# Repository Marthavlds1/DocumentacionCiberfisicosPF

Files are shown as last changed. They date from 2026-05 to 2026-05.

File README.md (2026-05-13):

# Planchado Express — Documentación Técnica

Documentación técnica del proyecto **Planchado Express**, desarrollado como parte de la asignatura de **Sistemas Ciberfísicos** en la **Universidad Iberoamericana (IBERO)**, Primavera 2026.

---

## Documentación en línea

La documentación completa del proyecto está disponible en:

**[marthavlds1.github.io/DocumentacionCiberfisicosPF](https://marthavlds1.github.io/DocumentacionCiberfisicosPF)**

---

## Descripción del proyecto

Planchado Express es un sistema ciberfísico integrado que automatiza el proceso de planchado de prendas textiles en un entorno industrial. El usuario registra su prenda en la interfaz web y obtiene un código QR de seguimiento; a partir de ese momento el sistema opera de forma completamente autónoma: clasifica la prenda mediante inteligencia artificial, ejecuta la rutina de planchado con un robot colaborativo UR3 y entrega la prenda mediante una banda transportadora con actuadores de salida.

### Componentes principales del sistema

| Componente | Tecnología |
| :--- | :--- |
| Robot colaborativo | Universal Robots UR3 |
| Control industrial | PLC Allen Bradley Micro850 |
| Orquestador del sistema | Raspberry Pi 3 — `rutina_maestra.py` |
| Clasificación por IA | Keras / TensorFlow — `keras_model.h5` |
| Control de periféricos | ESP32 (pistón eléctrico + torreta de señalización) |
| Base de datos y autenticación | Firebase (Auth, Firestore, Realtime DB, Storage) |
| Backend API | Flask — Docker — Render |
| Interfaz web del cliente | GitHub Pages |

---

## Estructura del repositorio

```
DocumentacionCiberfisicosPF/
├── _config.yml
├── _includes/
│   ├── head_custom.html
│   └── footer_custom.html
├── assets/
│   └── css/custom.css
├── index.md
├── 01-contexto.md
├── 02-problema.md
├── 03-objetivos.md
├── 04-descripcion-funcional.md
├── 05-algoritmo.md
├── 06-arquitectura.md
├── 07-diseno-mecanico.md
├── 08-diseno-electronico.md
├── 09-control-programacion.md
├── 10-iot-nube-interfaz.md
├── 11-simulacion.md
├── 12-materiales-costos.md
├── 13-metodologia.md
├── 14-resultados.md
├── 15-problemas.md
├── 16-evidencia.md
├── 17-referencias.md
└── uso-ia.md
```
---

## Equipo de desarrollo

| Integrante | Programa |
| :--- | :--- |
| Luis Cortés Muñoz | Ingeniería Mecatrónica — IBERO |
| Emmanuel Iturbide Rebolledo | Ingeniería Mecatrónica — IBERO |
| Alexander Moncada Rivas | Ingeniería Mecatrónica — IBERO |
| Martha Valdés Cruz | Ingeniería Mecatrónica — IBERO |
| Renata Badillo Cabrera | Ingeniería Mecatrónica — IBERO |
| Camila Sánchez Guevara | Ingeniería Mecatrónica — IBERO |

**Cuerpo docente:** Mtro. Joel Arango Ramírez · Dr. Huber Girón Nieto

---

## Referencias del proyecto

| Recurso | URL |
| :--- | :--- |
| Documentación técnica | [marthavlds1.github.io/DocumentacionCiberfisicosPF](https://marthavlds1.github.io/DocumentacionCiberfisicosPF) |
| Interfaz web del cliente | [luiscortesmunoz.github.io/Planchaduria](https://luiscortesmunoz.github.io/Planchaduria/) |
| Backend API (Render) | [docker-planchaduria.onrender.com](https://docker-planchaduria.onrender.com) |
| Diagrama de arquitectura | [Miro — Arquitectura Ciberfísica](https://miro.com/app/live-embed/uXjVGEpRJUk=/) |

---

## Tecnologías utilizadas

`Python` `URScript` `Flask` `Firebase` `Docker` `Keras` `TensorFlow` `Modbus TCP` `Raspberry Pi` `ESP32` `PLC Micro850` `Jekyll` `Just the Docs`

---

Universidad Iberoamericana · Ingeniería Mecatrónica · Sistemas Ciberfísicos · Primavera 2026

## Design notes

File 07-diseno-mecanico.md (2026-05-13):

---
layout: default
title: Diseño Mecánico
nav_order: 8
---

# Diseño Mecánico

## Estructura general del sistema

La estructura física de **Planchado Express** está compuesta por una **banda transportadora lineal** con tres estaciones de sensado y una plataforma de montaje para el robot UR3. El recorrido de la prenda va desde la entrada (sensor S1) hasta la salida por gancho (sensor S3).

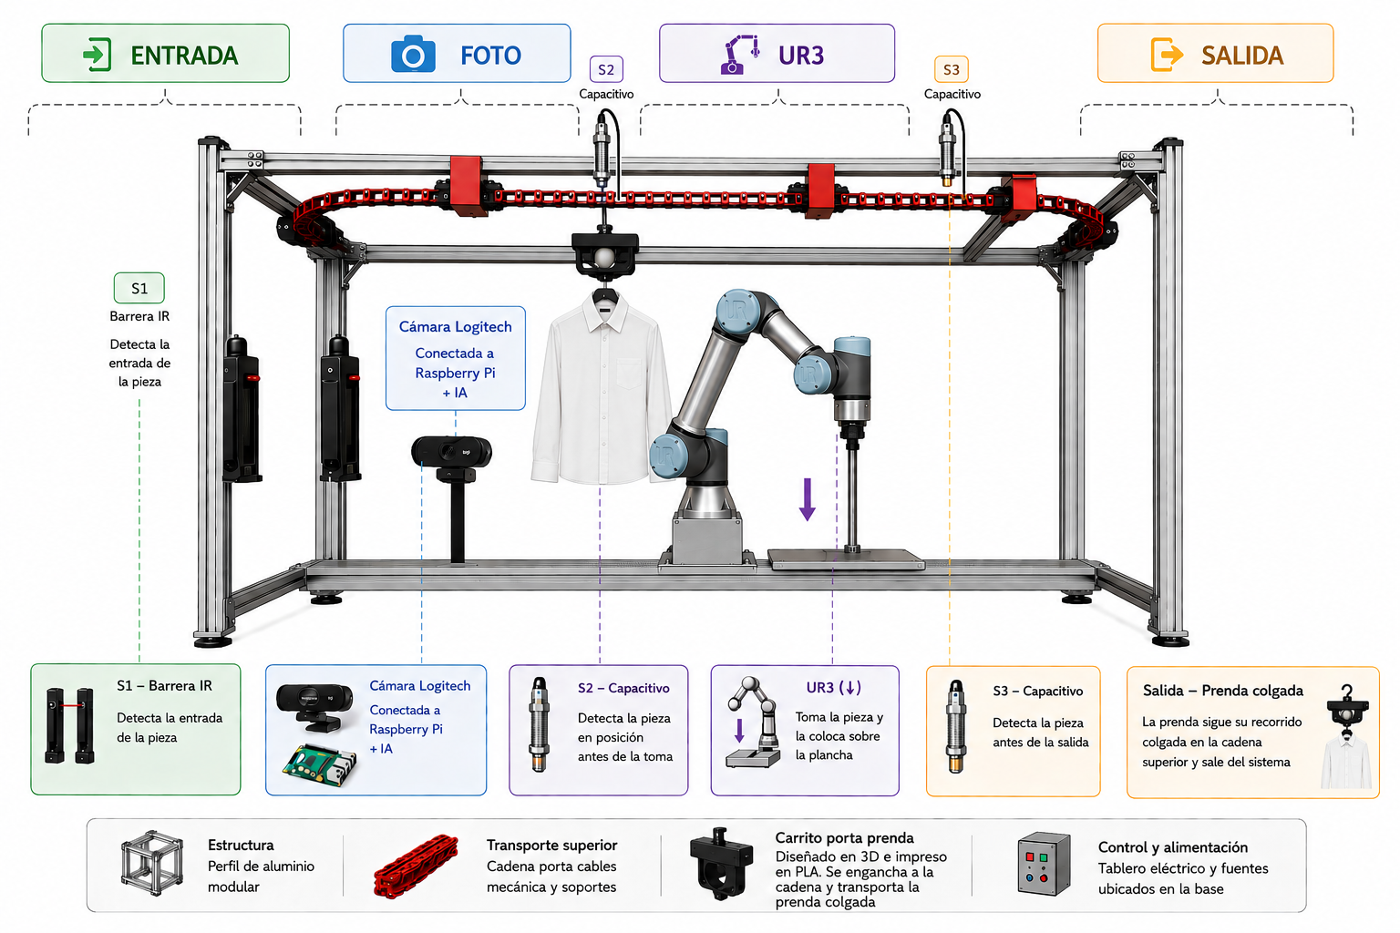
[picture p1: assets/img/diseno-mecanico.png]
Estructura general del sistema

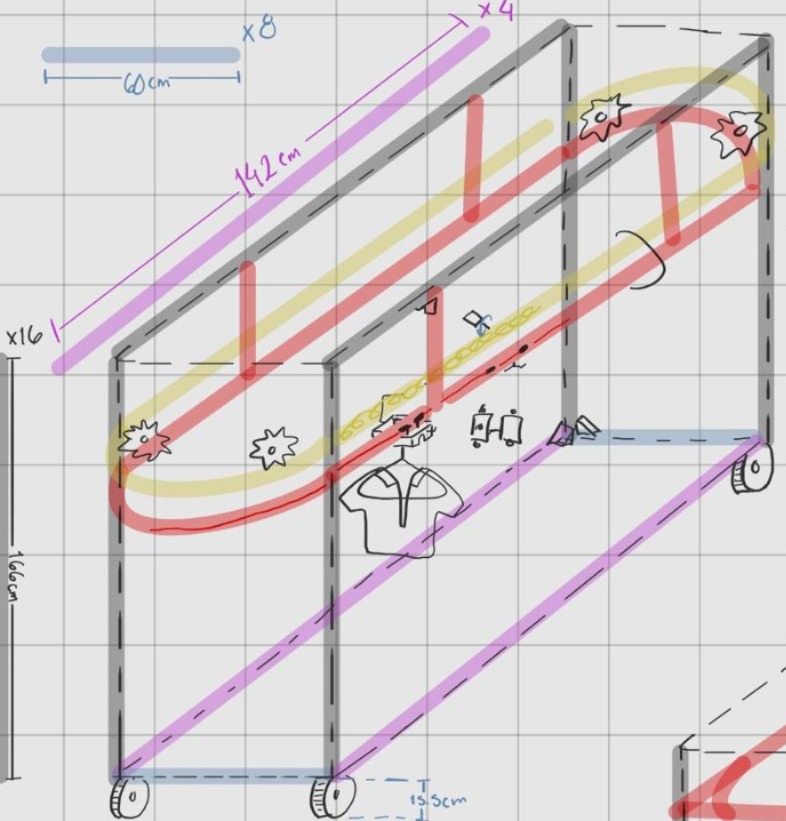
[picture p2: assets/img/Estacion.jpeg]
Medidas de estacion


---

## Robot UR3 — Especificaciones físicas

| Parámetro | Valor |
| :--- | :--- |
| Modelo | Universal Robots UR3 |
| Tipo | Robot colaborativo (Cobot) |
| Grados de libertad | 6 DOF |
| TCP configurado | `p[0.0, 0.0, 0.0777, 0.0, 0.0, 0.0]` |
| Payload configurado | 0.1 kg |
| Voltaje de herramienta | 24 V |
| Gravedad configurada | `[0.0, 0.0, 9.82]` m/s² |
| Efector final | Agarrador impreso en PLA (fabricación propia) |
| Herramienta montada | Plancha eléctrica comercial |
| Waypoints por rutina | 7 puntos calibrados |

---

## Efector final — Agarrador PLA

El agarrador del efector final fue **diseñado y fabricado mediante impresión 3D** en filamento PLA. Está dimensionado para:

- Sostener con seguridad la plancha comercial utilizada.
- Garantizar la geometría de contacto correcta con la superficie de la prenda durante las trayectorias de planchado.
- Resistir el peso y el calor transmitido por la plancha durante la operación continua.

---

## Banda transportadora

| Parámetro | Descripción |
| :--- | :--- |
| Tipo | Banda lineal motorizada |
| Dirección | Unidireccional (adelante) |
| Control | PLC Micro850 (coils `000001`, `000002`, `000003`) |
| Estaciones | Entrada → Foto → UR3 → Salida |
| Mecanismo de salida | Pistón eléctrico + gancho lateral |

---

## Actuador de salida — Pistón eléctrico

El pistón eléctrico está controlado por el **ESP32** mediante comandos seriales desde la Raspberry Pi. Al activarse, empuja lateralmente la prenda planchada hacia el gancho de salida donde el cliente la recoge.

| Parámetro | Valor |
| :--- | :--- |
| Tipo | Actuador lineal eléctrico |
| Control | ESP32 vía serial USB |
| Tiempo extendido | 9 segundos |
| Tiempo de espera tras cerrar | 9 segundos |
| Función | Expulsar prenda al gancho de salida |

---

## Piezas diseñadas e impresas en 3D

Todas las piezas fueron diseñadas en CAD y fabricadas mediante impresión 3D en filamento PLA. Los archivos `.stl` están disponibles en la carpeta `0_IMPRIMIR/` del repositorio.

[Descargar archivos STL](assets/0_IMPRIMIR){: .btn .btn-outline }

| Pieza | Vista previa | Función |
| :--- | :---: | :--- |
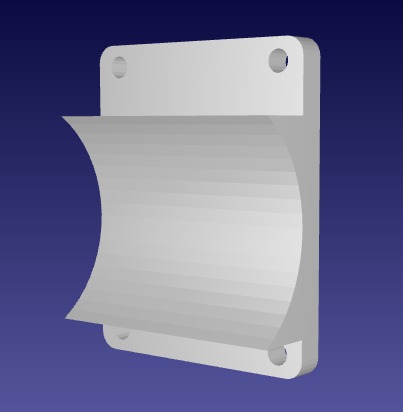
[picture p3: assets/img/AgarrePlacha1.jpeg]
Agarre Plancha 1
| Agarre de Plancha 1 |  | Sujeción principal de la plancha al efector del UR3 |
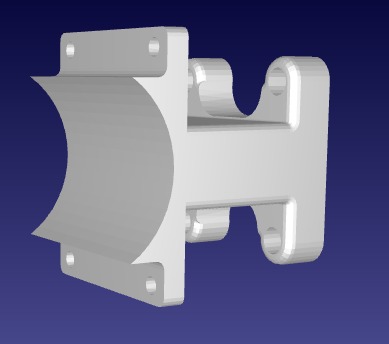
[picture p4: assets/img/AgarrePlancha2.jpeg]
Agarre Plancha 2
| Agarre de Plancha 2 |  | Pieza complementaria del agarre de plancha |
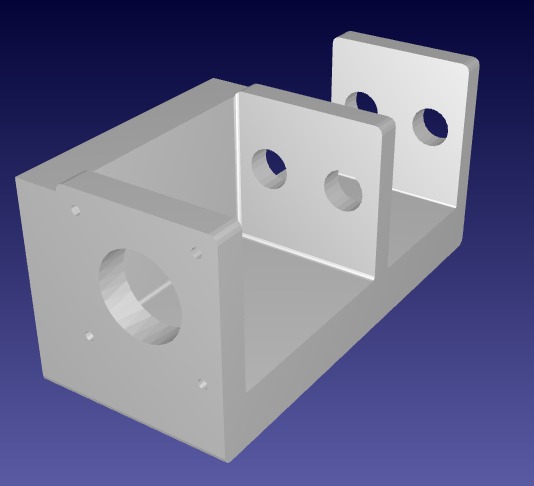
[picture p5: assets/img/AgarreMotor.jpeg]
Agarre Motor
| Agarre Motor a Pasos |  | Montaje del motor Nema 17 en la estructura |
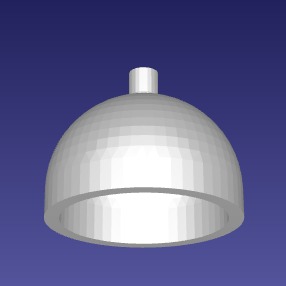
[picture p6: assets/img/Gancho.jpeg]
Gancho
| Gancho |  | Gancho de salida para entrega de prenda |
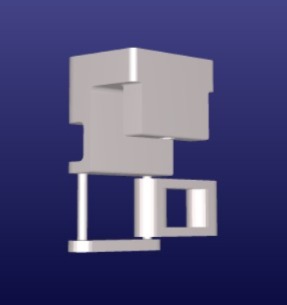
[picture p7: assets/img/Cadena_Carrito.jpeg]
Cadena Ganchito
| Cadena Ganchito |  | Eslabón de cadena para sistema de transporte |
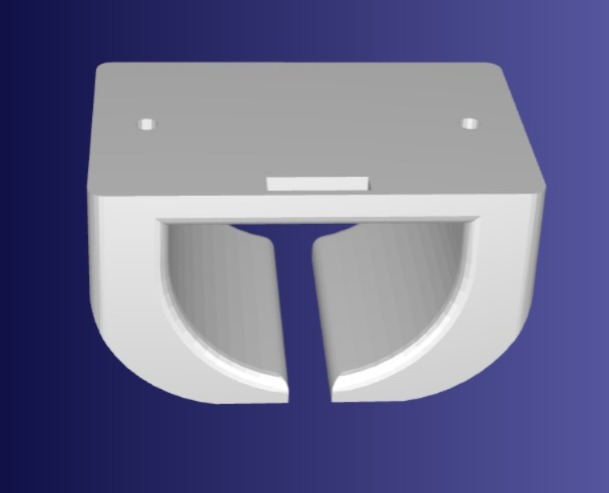
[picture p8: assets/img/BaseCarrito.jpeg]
Carrito Base
| Carrito Base |  | Base del carrito sobre la banda |
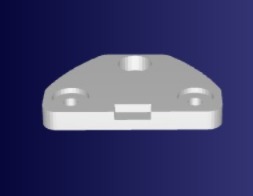
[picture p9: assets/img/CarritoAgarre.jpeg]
Carrito Agarre
| Carrito Agarre |  | Agarre superior del carrito |
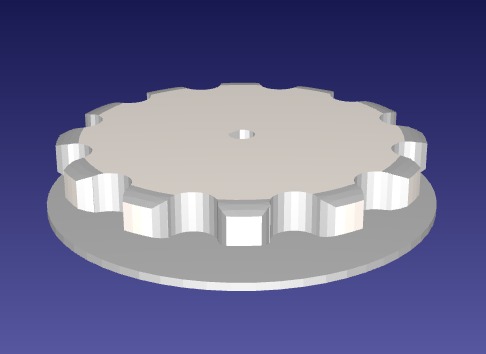
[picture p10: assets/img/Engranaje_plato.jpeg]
Engranaje Plato
| Engranaje Plato |  | Engranaje de transmisión principal |
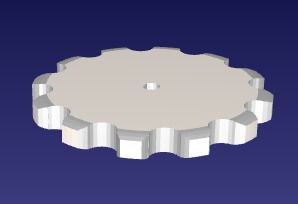
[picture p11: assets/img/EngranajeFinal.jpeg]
Engranaje Final
| Engranaje Final |  | Engranaje de salida del sistema |
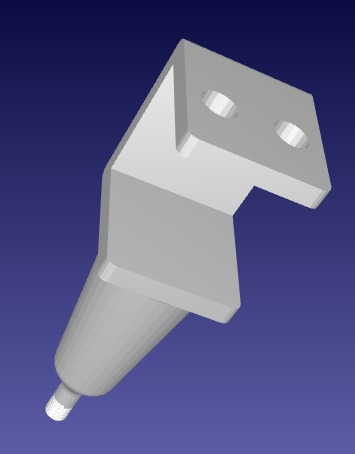
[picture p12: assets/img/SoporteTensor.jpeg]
Soporte Tensor
| Soporte Tensor |  | Soporte para sistema de tensado de banda |
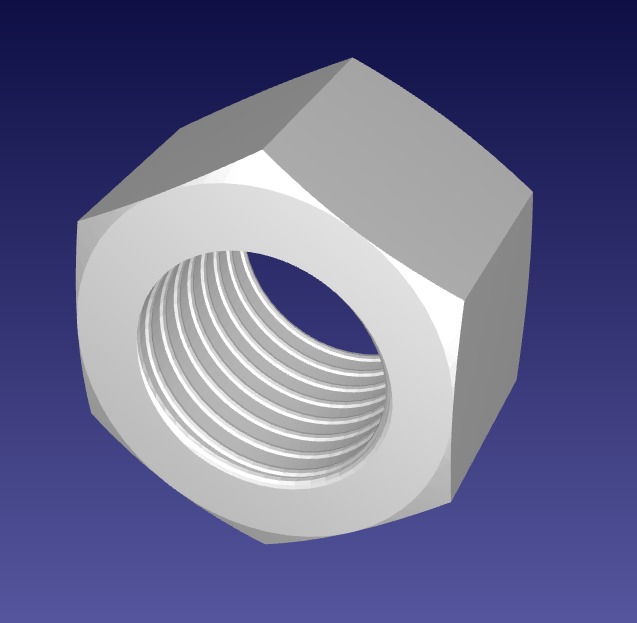
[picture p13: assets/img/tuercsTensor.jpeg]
Tuerca Tensor
| Tuerca Tensor |  | Elemento de ajuste del tensor |
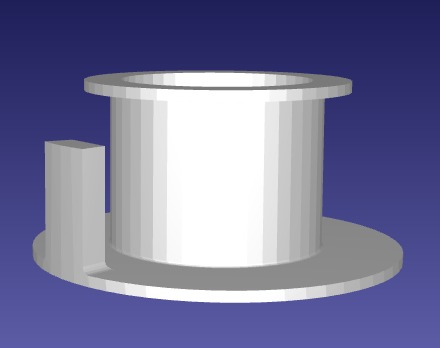
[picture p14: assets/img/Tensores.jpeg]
Tensores
| Tensores |  | Componentes de tensado de la banda |
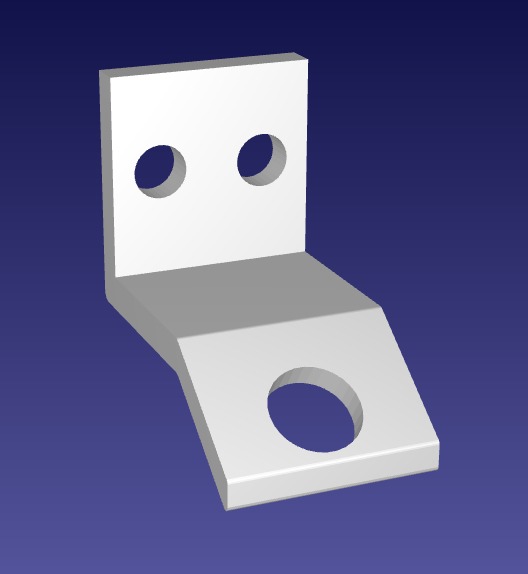
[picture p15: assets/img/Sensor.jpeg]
Sensores
| Sensores |  | Soporte/montaje para sensores inductivos |
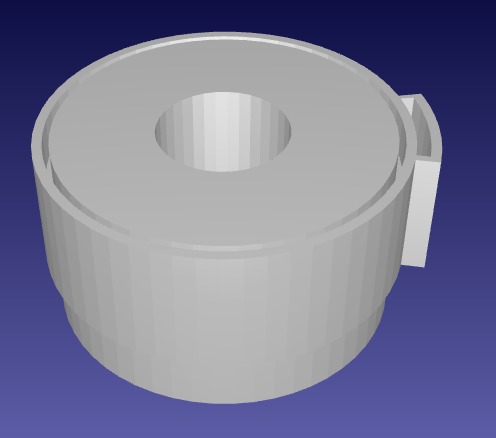
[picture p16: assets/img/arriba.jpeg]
Soporte acetato superior
| Soporte acetato sup. |  | Soporte superior lateral de acetato |
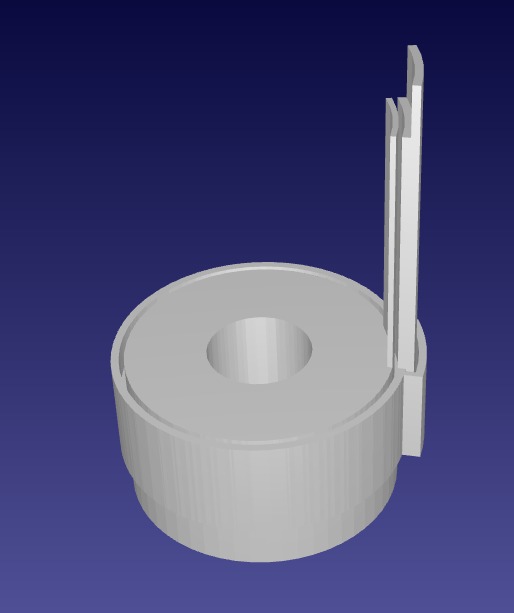
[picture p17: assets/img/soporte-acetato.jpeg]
Soporte acetato
| Soporte acetato |  | Soporte lateral de acetato |
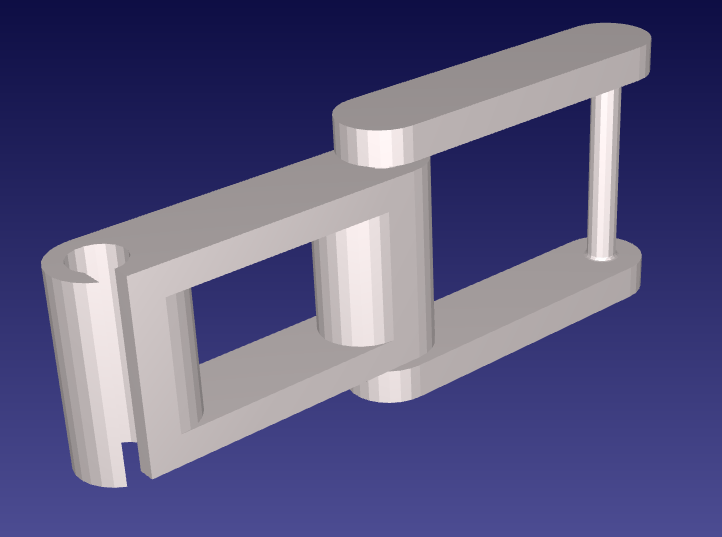
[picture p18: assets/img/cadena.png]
Eslabon Cadena
| Eslabón Cadena |  | Eslabón de Cadena |

---

## Siguiente sección

[Diseño Electrónico](08-diseno-electronico.md)

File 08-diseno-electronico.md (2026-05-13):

---
layout: default
title: Diseño Electrónico
nav_order: 9
---

# Diseño Electrónico

## Diagrama de cableado — Sistema de control mecatrónico

**PLC Allen Bradley Micro850 QWB · Driver TB6600 · Motor NEMA 17 · Sensores · Plancha 120 VAC**

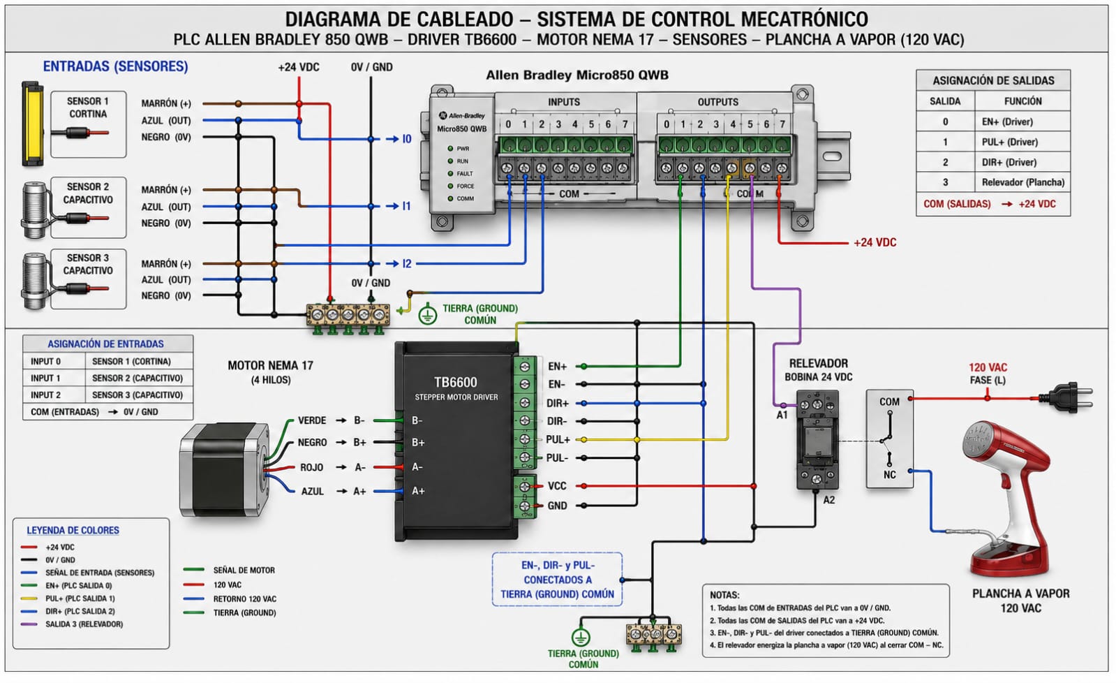
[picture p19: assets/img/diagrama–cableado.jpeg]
Diagrama de cableado — Sistema de control mecatrónico


### Entradas del PLC (Inputs)

| Input | Componente | Tipo | Conexión |
| :---: | :--- | :--- | :--- |
| I0 | Sensor 1 — Cortina | Digital NPN | Señal (azul OUT) → I0 · Marrón (+) → +24 V · Negro → 0 V |
| I4 | Sensor 2 — Capacitivo | Digital NPN | Señal (azul OUT) → I4 · Marrón (+) → +24 V · Negro → 0 V |
| I5 | Sensor 3 — Capacitivo | Digital NPN | Señal (azul OUT) → I5 · Marrón (+) → +24 V · Negro → 0 V |
| COM | Tierra común entradas | — | Todas las COM de entradas → 0 V / GND |

### Salidas del PLC (Outputs)

| Output | Función | Destino | Observación |
| :---: | :--- | :--- | :--- |
| O0 | EN+ (Driver) | TB6600 — terminal EN+ | Habilita el driver del motor |
| O1 | PUL+ (Driver) | TB6600 — terminal PUL+ | Pulsos de paso del motor |
| O2 | DIR+ (Driver) | TB6600 — terminal DIR+ | Dirección de giro |
| O3 | Relevador (Plancha) | Bobina A1 del relevador 24 VDC | Activa la plancha 120 VAC al cerrar COM–NC |
| COM | Alimentación salidas | +24 VDC | Todas las COM de salidas → +24 V |

### Conexión Motor NEMA 17 → Driver TB6600

| Cable motor | Terminal driver | Color |
| :--- | :--- | :--- |
| B− | B− del TB6600 | Verde |
| B+ | B+ del TB6600 | Negro |
| A− | A− del TB6600 | Rojo |
| A+ | A+ del TB6600 | Azul |

### Conexión Driver TB6600 — Potencia y tierra

| Terminal driver | Conexión | Observación |
| :--- | :--- | :--- |
| VCC | +24 VDC | Alimentación del driver |
| GND | 0 V / GND | Retorno de potencia |
| EN− | Tierra común | Conectar a GND común del panel |
| DIR− | Tierra común | Conectar a GND común del panel |
| PUL− | Tierra común | Conectar a GND común del panel |

{: .note }
EN−, DIR− y PUL− deben conectarse a la misma barra de tierra común del panel de clemas.

### Relevador — Activación de la plancha 120 VAC

| Terminal | Conexión |
| :--- | :--- |
| A1 (bobina +) | Salida O3 del PLC |
| A2 (bobina −) | 0 V / GND |
| COM (contacto) | Fase 120 VAC (L) |
| NC (contacto) | Terminal de la plancha |

{: .warning }
La plancha opera a **120 VAC**. El relevador aísla el circuito de control (24 VDC) del circuito de potencia (120 VAC). El contacto NC se cierra cuando el relevador se energiza, activando la plancha.

### Notas generales del cableado

1. Todas las COM de entradas del PLC van a **0 V / GND**.
2. Todas las COM de salidas del PLC van a **+24 VDC**.
3. EN−, DIR− y PUL− del driver TB6600 conectados a **tierra común**.
4. El relevador energiza la plancha a vapor (120 VAC) al cerrar el contacto COM–NC.

---

## Arquitectura electrónica general

El sistema electrónico se organiza en tres capas:

1. **Sensado** — detección del estado físico de la prenda en la línea
2. **Control industrial** — PLC Micro850 gestiona motor, sensores y actuadores
3. **Actuación periférica** — ESP32 controla pistón y torreta; UR3 plancha

---

## Sensores

| Sensor | Tipo | Posición | Función | Dirección PLC |
| :--- | :--- | :--- | :--- | :--- |
| **S1** | Barrera infrarroja | Entrada de banda | Detecta presencia de prenda al iniciar el proceso | `000004` |
| **S2** | Inductivo | Estación UR3 | Confirma posición de la prenda bajo el robot | `000005` |
| **S3** | Inductivo | Estación de salida | Marca fin del proceso — activa pistón | `000006` |

### S1 — Sensor de barrera infrarroja
Sensor fotoeléctrico de barrera (emisor/receptor) ubicado en la entrada de la banda transportadora. Cuando la prenda interrumpe el haz de luz infrarroja, el PLC recibe la señal en la dirección `000004` y activa el motor de la banda.

### S2 y S3 — Sensores inductivos
Sensores de proximidad inductivos que detectan la presencia de material metálico (estructura de la banda o porta-prenda). Se utilizan para posicionar la prenda en la estación de planchado (S2) y en la estación de salida (S3).

{: .note }
El sistema implementa un **filtro de debounce** con 3 lecturas consecutivas en 50 ms para cada sensor, eliminando falsas detecciones por ruido eléctrico o rebotes mecánicos.

---

## PLC Allen Bradley Micro850

| Parámetro | Valor |
| :--- | :--- |
| Modelo | Allen Bradley Micro850 |
| Software de programación | Connected Components Workbench (CCW) |
| Protocolo de comunicación | Modbus TCP |
| IP en red local | `192.168.3.151` |
| Puerto Modbus | `502` |
| Unit ID | `1` |
| Entradas digitales | S1 (`000004`), S2 (`000005`), S3 (`000006`) |
| Salidas digitales | Motor START (`000001`), Motor STOP (`000002`), Dirección FWD (`000003`), Plancha (`000007`) |

### Mapa de direcciones Modbus (offset base 0)

```python
COIL_CMD_START      = 0   # 000001 — Arrancar motor
COIL_CMD_STOP       = 1   # 000002 — Parar motor
COIL_CMD_DIR_FWD    = 2   # 000003 — Dirección hacia adelante
SENSOR1_ADDRESS     = 3   # 000004 — Sensor barrera IR (entrada)
SENSOR2_ADDRESS     = 4   # 000005 — Sensor inductivo (posición UR3)
SENSOR3_ADDRESS     = 5   # 000006 — Sensor inductivo (salida)
SALIDA_AUX_PLANCHA  = 6   # 000007 — Activar/desactivar plancha
```

---

## Actuadores

| Actuador | Control | Dirección | Función |
| :--- | :--- | :--- | :--- |
| Motor de banda | PLC Micro850 | `000001/002/003` | Arranque, paro y dirección de la banda transportadora |
| Plancha eléctrica | PLC Micro850 | `000007` | Activación de la resistencia calefactora |
| Robot UR3 | URScript + Modbus | `192.168.3.71:30002` | Ejecución de trayectorias de planchado |
| Pistón eléctrico | ESP32 vía serial | `COM3` | Empuja la prenda hacia el gancho de salida |
| Torreta luminosa | ESP32 vía serial | `COM3` | Señalización visual del estado del sistema |

---

## ESP32 — Periféricos de salida

| Parámetro | Valor |
| :--- | :--- |
| Microcontrolador | ESP32 |
| Comunicación | Serial USB / 115200 baud |
| Puerto serial | `COM3` |
| Controla | Pistón eléctrico + Torreta LED |
| Tiempo de activación del pistón | 9 segundos extendido |
| Timeout serial | 1 segundo |

### Diseño PCB para ESP32

Se diseñó una tarjeta de circuito impreso (PCB) personalizada para integrar el módulo **XIAO ESP32-S3** con los actuadores del sistema. La PCB incorpora un puente H **L298N** para el manejo de corriente del pistón eléctrico, diodos de protección **1N4007** en configuración flyback para suprimir picos inductivos, conectores de tornillo para la torreta LED y el pistón, un LED indicador de estado y los capacitores de desacople necesarios para la estabilidad del circuito. El diseño centraliza en una sola placa la lógica de control del ESP32 y la etapa de potencia de los actuadores, simplificando el cableado del tablero y reduciendo el riesgo de conexiones sueltas durante la operación del sistema.

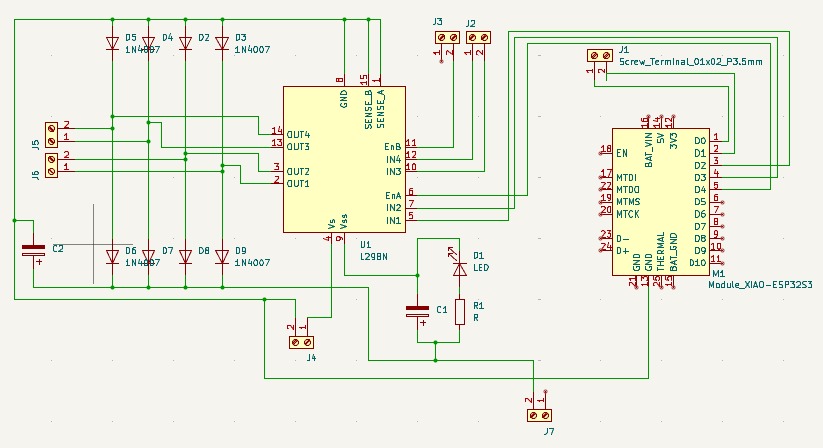
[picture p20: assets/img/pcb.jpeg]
Esquemático PCB — ESP32, L298N, pistón y torreta


[Descargar PCB\_ESP32.zip](assets/files/PCB_ESP32.zip)

---

## Raspberry Pi 3 — Nodo de cámara e IA

Una segunda Raspberry Pi 3 opera como **nodo independiente de cámara e inteligencia artificial**:

| Parámetro | Valor |
| :--- | :--- |
| IP en red local | `192.168.3.162` |
| Puerto Flask | `5000` |
| Función | Captura fotográfica + clasificación IA |
| Modelo IA | `keras_model.h5` (Keras/TensorFlow) |
| Tamaño de imagen al modelo | 224 × 224 px |
| Clases | `0 Camisa` / `1 Playera` |

---

## Recursos asociados

### motor_sensor.zip
Código del sistema embebido basado en ESP32 para el control de actuadores (pistón y torreta).

[Descargar motor_sensor.zip](assets/files/motor_sensor.zip)

---

## Siguiente sección

[Control y Programación](09-control-programacion.md)

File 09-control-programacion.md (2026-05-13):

---
layout: default
title: Control y Programación
nav_order: 10
---

# Control y Programación

## Capas de software del sistema

El sistema distribuye el control en cuatro capas de software que operan coordinadamente:

| Capa | Archivo | Tecnología | Función |
| :--- | :--- | :--- | :--- |
| Orquestador | [rutina_maestra.py](assets/files/rutina_maestra.py) | Python / Raspberry Pi | Coordina todo el proceso |
| Control de campo | Proyecto CCW | PLC Micro850 / Ladder | Motor, sensores, plancha |
| Robótica | [`camisa.script`](assets/files/camisa.script) / [`playera.script`](assets/files/playera.script) | URScript | Trayectorias UR3 |
| Periféricos | Firmware ESP32 | C++ / Arduino | Pistón + Torreta |

---

## rutina_maestra.py — Orquestador central

El archivo [rutina_maestra.py](assets/files/rutina_maestra.py) es el **cerebro del sistema**. Implementa una máquina de estados explícita que coordina todos los subsistemas.

### Librerías principales

```python
from pymodbus.client import ModbusTcpClient  # Comunicación PLC y UR3
import requests                               # API REST → Render/Firebase
import serial                                 # Comunicación ESP32
import socket                                 # Envío scripts al UR3
import tf_keras as keras                      # Modelo IA de clasificación
from PIL import Image                         # Procesamiento de imagen
```

### Gestión de etapas

```python
def cambiar_etapa(nueva_etapa: str):
    global etapa_actual
    etapa_actual = nueva_etapa
    print(f"[ESTADO] Etapa actual -> {etapa_actual}")

def configurar_mascaras_sensores(s1: bool, s2: bool, s3: bool):
    global sensor1_habilitado, sensor2_habilitado, sensor3_habilitado
    sensor1_habilitado = s1
    sensor2_habilitado = s2
    sensor3_habilitado = s3
    print(f"[MASCARAS] S1={'ON' if s1 else 'OFF'} | S2={'ON' if s2 else 'OFF'} | S3={'ON' if s3 else 'OFF'}")
```

### Clasificación IA de prendas

```python
def clasificar_prenda(imagen_path):
    img = Image.open(imagen_path).resize((224, 224))
    data = np.array(img, dtype=np.float32) / 127.5 - 1
    prediction = modelo_prendas.predict(data[np.newaxis, ...])
    clase_idx = np.argmax(prediction)
    confianza  = prediction[0][clase_idx]
    return labels_prendas[clase_idx], confianza
    # Retorna: ("Camisa", 0.97) o ("Playera", 0.94)
```

### Envío de script URScript al robot

```python
def enviar_script_ur3(ruta_script: str):
    with open(ruta_script, "r") as f:
        script = f.read()
    sock = socket.socket()
    sock.connect((ROBOT_IP, ROBOT_PORT))   # 192.168.3.71:30002
    sock.sendall(script.encode())
    sock.close()
```

### Control del motor (PLC Micro850 vía pymodbus)

```python
def motor_start():
    with ModbusTcpClient(PLC_IP, port=PLC_PORT) as client:
        client.write_coil(COIL_CMD_DIR_FWD, True, slave=PLC_UNIT_ID)
        client.write_coil(COIL_CMD_START,   True, slave=PLC_UNIT_ID)
    print("[PLC] Motor iniciado")

def motor_stop():
    with ModbusTcpClient(PLC_IP, port=PLC_PORT) as client:
        client.write_coil(COIL_CMD_STOP, True, slave=PLC_UNIT_ID)
    print("[PLC] Motor detenido")
```

---

## URScript — Trayectorias del UR3

### camisa.script (resumen)

Rutina de planchado para camisas de vestir. Define 7 waypoints con movimientos `movej` + cinemática inversa (`get_inverse_kin`).

```
def camisa():
  set_tcp(p[0.0, 0.0, 0.0777, 0.0, 0.0, 0.0])
  set_payload(0.1, [0.0, 0.0, 0.08])
  set_tool_voltage(24)
  modbus_add_signal("192.168.3.71", 255, 129, 3, "RX74", False)
  modbus_add_signal("192.168.3.133", 255, 130, 3, "TX71", False)

  while (True):
    movej(get_inverse_kin(p[.062, .299, .603, -1.834, -.149, -.019], ...), a=1.396, v=1.047)
    movej(get_inverse_kin(p[.023, .321, .271, -1.863, -.037, .140], ...), a=1.396, v=1.047)
    movej(get_inverse_kin(p[.092, .279, .548, -1.786, -.042, -.080], ...), a=1.396, v=1.047)
    movej(get_inverse_kin(p[.083, .283, .262, -1.995, -.014, -.012], ...), a=1.396, v=1.047)
    movej(get_inverse_kin(p[.167, .265, .509, -1.935,  .245, -.242], ...), a=1.396, v=1.047)
    movej(get_inverse_kin(p[.183, .239, .233, -2.204,  .277, -.134], ...), a=1.396, v=1.047)
    movej(get_inverse_kin(p[.015, .272, .692, -1.570,  .003,  .159], ...), a=1.396, v=1.047)
  end
end
```

### playera.script (resumen)

Rutina análoga para playeras con waypoints re-calibrados para la geometría diferente de este tipo de prenda.

### Parámetros de movimiento

| Parámetro | Valor | Descripción |
| :--- | :--- | :--- |
| `a` | `1.3962 rad/s²` | Aceleración articular |
| `v` | `1.0471 rad/s` | Velocidad articular |
| TCP offset Z | `0.0777 m` | Distancia de la herramienta al flange |
| Payload | `0.1 kg` | Masa de la plancha |

---

## PLC Micro850 — Connected Components Workbench

La lógica del PLC fue desarrollada en **Connected Components Workbench (CCW)** de Rockwell Automation, utilizando lenguaje Ladder. Las funciones principales son:

- Arranque y paro del motor de la banda (con dirección)
- Lectura de los tres sensores digitales (S1, S2, S3)
- Activación de la salida `000007` para la plancha eléctrica
- Respuesta a los comandos Modbus TCP desde la Raspberry Pi

La siguiente imagen muestra una parte del programa en lenguaje Ladder utilizado para controlar el movimiento del motor dentro del sistema de planchado automatizado. Esta lógica permite activar el motor, definir su dirección de giro y generar los pulsos necesarios para el movimiento.

En la primera línea se realiza la lectura del sensor de entrada, identificado como `sensor1`. Este sensor permite detectar la presencia de una prenda en el sistema. Cuando el sensor cambia de estado, la señal puede ser utilizada por el PLC para iniciar la secuencia de trabajo.

Posteriormente, se observa una lógica de arranque y paro del motor. El contacto `CMD_START` permite activar la bobina `MOTOR_RUN`, mientras que `CMD_STOP` funciona como condición de paro. Además, se utiliza un contacto auxiliar de `MOTOR_RUN` para mantener enclavado el motor una vez que fue iniciado, evitando que se apague inmediatamente al soltar la señal de arranque.

También se incluye la señal `CMD_DIR_FWD`, la cual controla la dirección de giro del motor mediante la salida digital `_IO_EM_DO_01`. Esta salida se encarga de enviar la señal de dirección al controlador del motor.

Finalmente, se utilizan temporizadores tipo `TON` para generar una señal intermitente llamada `PULSE_BIT`. Esta señal funciona como el pulso que permite mover el motor paso a paso. Al alternar el estado de `PULSE_BIT`, el PLC puede enviar pulsos continuos al driver del motor mientras la señal `MOTOR_RUN` permanezca activa.

### Lógica Ladder para control de motor

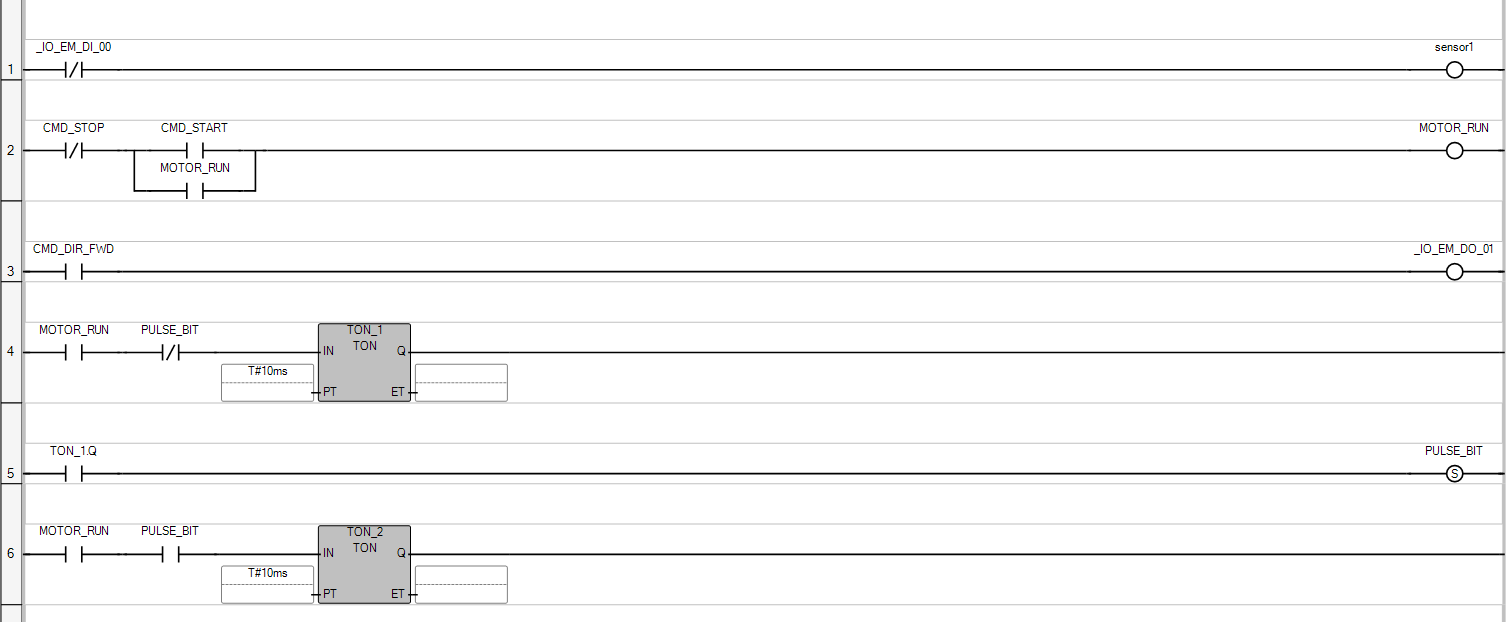
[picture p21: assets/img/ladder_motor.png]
Lógica Ladder para control de motor


**Figura 1.** Programa Ladder implementado en el PLC para controlar el arranque, paro, dirección y generación de pulsos del motor utilizado en el sistema de planchado automatizado.

---

## Dashboard de monitoreo — dashboard_server.py

El archivo [`dashboard_server.py`](assets/files/dashboard_server.py) implementa un **servidor Flask con Server-Sent Events (SSE)** que permite monitorear la rutina maestra en tiempo real sin modificarla:

- Ejecuta [`rutina_maestra.py`](assets/files/rutina_maestra.py) como subproceso.
- Lee su salida estándar e interpreta los `[ESTADO]`, `[PLC]`, `[IA]`, `[MASCARAS]` y `[PC]` tags.
- Emite el estado actualizado a todos los clientes web conectados vía SSE.
- Expone endpoints REST (`/api/status`, `/api/start`, `/events`).

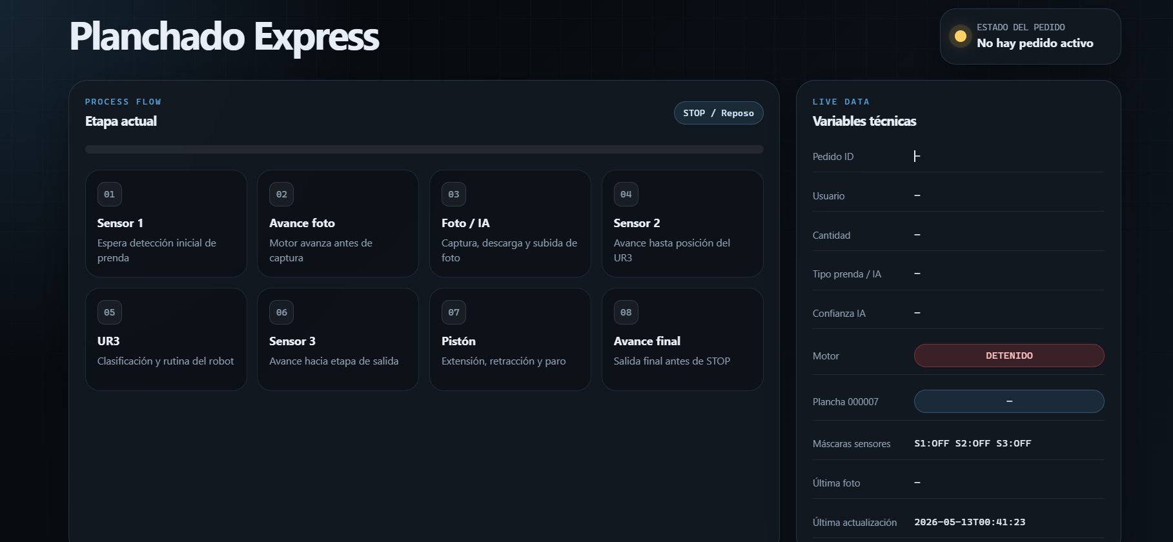
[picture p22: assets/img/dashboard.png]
Dashboard


**Figura 2.** Interfaz HMI para monitoreo del proceso de Planchado Express.

## Recursos asociados 

### motor_sensor.zip  
Código del sistema embebido basado en ESP32 para el control de actuadores (pistón y torreta).  
Descarga: [motor_sensor.zip](assets/files/motor_sensor.zip)
Este recurso contiene la implementación del control del ESP32, incluyendo la gestión de actuadores y la interacción con sensores. Se relaciona con ambas secciones ya que define tanto la arquitectura electrónica del sistema como la lógica de programación de los periféricos.
---

## Siguiente sección

[IoT / Nube / Interfaz Web](10-iot-nube-interfaz.md)

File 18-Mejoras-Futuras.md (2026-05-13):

---
layout: default
title: Mejoras Futuras
nav_order: 18
---

# Mejoras Futuras

A partir del desarrollo e integración del sistema de **Planchado Express**, se identificaron diferentes áreas de oportunidad que pueden mejorar el desempeño, la estabilidad y la escalabilidad del proyecto. Estas mejoras abarcan la parte de control, sensores, planchado, mecánica, estructura, electrónica y visión artificial.

---

## Programador lógico / PLC

Durante el desarrollo del sistema se utilizó el PLC disponible de acuerdo con los recursos del proyecto. Sin embargo, las salidas utilizadas (relevador) no fueron las más adecuadas para generar pulsos rápidos y precisos para el control del motor a pasos. Esto provocó que el movimiento del motor fuera más lento y que el control de velocidad tuviera ciertas limitaciones.

Como mejora futura, se propone utilizar un PLC con **salidas transistor de alta velocidad** o salidas especiales para control de pulsos. Esto permitiría generar señales más rápidas, mejorar la respuesta del motor a pasos y tener un control más preciso del movimiento.

También se debe considerar la ubicación y protección de los sensores, ya que algunos pueden verse afectados por la luz del medio ambiente. Para evitar lecturas falsas, se recomienda mejorar el montaje físico de los sensores, calibrarlos correctamente y, si es necesario, utilizar sensores con mayor inmunidad a la luz externa.

---

## Sistema de planchado

En la parte de planchado, una mejora importante sería utilizar una superficie más estable para sostener la playera o prenda durante el proceso. Actualmente, si la prenda no queda completamente fija, puede moverse o quedar suspendida, lo que afecta la calidad del planchado.

Como mejora futura, se propone diseñar una base donde la prenda permanezca bien extendida y fija durante todo el proceso. Además, se podrían agregar más pasadas de la plancha para mejorar el acabado final y asegurar que la prenda quede mejor planchada.

---

## Sistema mecánico

En la parte mecánica, se identificó que el movimiento podría mejorar utilizando componentes de mayor calidad. Una propuesta es invertir en una **cadena tipo bicicleta** y en **engranes nuevos**, ya que esto permitiría obtener un movimiento más uniforme, estable y confiable.

También se recomienda comprar más perfil estructural para completar y mejorar el rack de entrega. Esto permitiría tener una salida más ordenada de las prendas y facilitaría el proceso final después del planchado.

---

## Estructura del sistema

Para mejorar la firmeza de la estructura, se propone agregar perfiles en diagonal en zonas estratégicas. Esto ayudaría a reducir vibraciones, aumentar la rigidez del sistema y mejorar la estabilidad general durante el movimiento del motor, la plancha y los mecanismos de transporte.

Una estructura más rígida también permitiría que los sensores, el motor y los actuadores trabajen con mayor precisión, reduciendo errores causados por movimientos no deseados.

---

## PCB y torreta

En la parte electrónica, específicamente en la PCB y la torreta, se identificaron oportunidades de mejora en el diseño y armado del circuito. Debido al proceso de fabricación utilizado, se presentaron algunos problemas con la PCB, lo que dificultó alcanzar el funcionamiento deseado.

Como mejora futura, se propone rediseñar la PCB, revisar correctamente las conexiones y validar el circuito antes de fabricarlo. Además, se recomienda mandar a fabricar la PCB de manera profesional, por ejemplo, con un proveedor especializado, para obtener una placa con mejor calidad, mayor confiabilidad y menor probabilidad de fallas.

Esto permitiría que la torreta funcione correctamente y que las señales visuales del sistema, como los colores de estado, sean más claras y estables.

---

## Escalabilidad del sistema

Finalmente, una mejora importante sería implementar más carritos dentro del sistema para poder procesar más de una prenda al mismo tiempo. Esto permitiría aumentar la capacidad del sistema y hacerlo más eficiente en un entorno de producción.

Además, se podría ampliar la red neuronal utilizada para la clasificación de prendas, agregando más tipos de ropa como sacos, pantalones u otras prendas. Con un modelo más completo, el sistema podría tomar mejores decisiones y adaptarse a una mayor variedad de casos reales.

---

## Conclusión

Las mejoras futuras propuestas permitirían que el sistema de Planchado Express sea más rápido, estable y confiable. Al optimizar el PLC, mejorar la estructura mecánica, rediseñar la PCB, fijar mejor la prenda durante el planchado y ampliar la capacidad del sistema, el proyecto podría evolucionar hacia una versión más robusta y cercana a una aplicación industrial real.

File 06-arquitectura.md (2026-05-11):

---
layout: default
title: Arquitectura Ciberfísica
nav_order: 7
---

# Arquitectura Ciberfísica

{: .highlight }
Esta es la sección más importante del proyecto. La arquitectura ciberfísica define cómo cada componente físico y digital se comunica, qué protocolo utiliza y cuál es su rol dentro del sistema integrado.

---

## Visión general

El sistema **Planchado Express** es un sistema ciberfísico (CPS) compuesto por **cinco capas de comunicación** que operan de forma simultánea y coordinada:

| Capa | Componentes | Protocolo |
| :--- | :--- | :--- |
| **Nube / Internet** | Firebase, Render (Flask), GitHub Pages | HTTPS / REST / Firebase SDK |
| **Coordinación local** | Raspberry Pi 3 ([`rutina_maestra.py`](assets/files/rutina_maestra.py)) | Python / HTTP / Modbus / Serial |
| **HMI** | Raspberry Pi 3 + pantalla táctil + cámara QR | HTTPS → Firebase |
| **Control industrial** | PLC Allen Bradley Micro850 | Modbus TCP |
| **Robótica y periféricos** | UR3, ESP32, sensores, motor, pistón | Modbus TCP, Serial USB |

---

## Diagrama de arquitectura

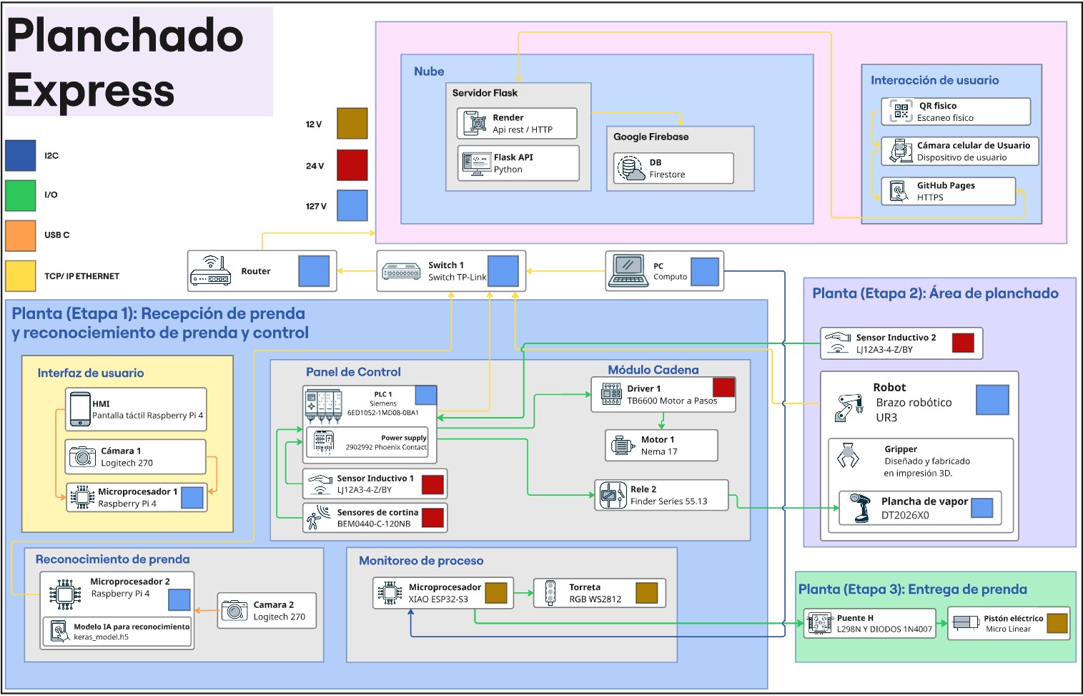
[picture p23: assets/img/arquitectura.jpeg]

---

## Protocolos de comunicación

### Modbus TCP — PLC Micro850

El PLC Allen Bradley Micro850 se comunica con la Raspberry Pi mediante **Modbus TCP**, utilizando la librería `pymodbus` en Python.

```python
PLC_IP      = "192.168.3.151"
PLC_PORT    = 502
PLC_UNIT_ID = 1

# Coils de salida (control)
COIL_CMD_START    = 0   # 000001 — Arrancar motor
COIL_CMD_STOP     = 1   # 000002 — Parar motor
COIL_CMD_DIR_FWD  = 2   # 000003 — Dirección adelante
SALIDA_AUX_PLANCHA = 6  # 000007 — Activar plancha

# Entradas digitales (lectura de sensores)
SENSOR1_ADDRESS = 3     # 000004 — Barrera IR
SENSOR2_ADDRESS = 4     # 000005 — Inductivo UR3
SENSOR3_ADDRESS = 5     # 000006 — Inductivo salida
```

### Modbus TCP — Robot UR3

El UR3 también utiliza Modbus TCP para comunicarse con la Raspberry Pi. Adicionalmente, los scripts URScript se envían directamente al robot mediante un **socket TCP** al puerto `30002`.

```python
ROBOT_IP   = "192.168.3.71"
ROBOT_PORT = 30002

# Señales Modbus del UR3 (definidas dentro del script URScript)
modbus_add_signal("192.168.3.71", 255, 129, 3, "RX74", False)
modbus_add_signal("192.168.3.133", 255, 130, 3, "TX71", False)
```

### HTTP REST — Raspberry Pi cámara

La Raspberry Pi orquestadora solicita la fotografía a la Raspberry Pi de cámara mediante una API Flask local:

```python
RASPBERRY_IP   = "192.168.3.162"
RASPBERRY_PORT = 5000
BASE_RPI       = f"http://{RASPBERRY_IP}:{RASPBERRY_PORT}"
```

### Serial USB — ESP32

El ESP32 recibe comandos de la Raspberry Pi mediante comunicación serial para controlar la **torreta de señalización** y el **pistón eléctrico**:

```python
ESP32_SERIAL_PORT = "COM3"
ESP32_BAUDRATE    = 115200
ESP32_TIMEOUT     = 1
```

### HTTPS/REST — Backend en Render (nube)

La rutina maestra se comunica con el backend Flask desplegado en Render para sincronizar el estado con Firebase y subir las fotografías de evidencia:

```python
RENDER_BASE_URL = "https://docker-planchaduria.onrender.com"
```

---

## Tabla de IPs y puertos del sistema

| Componente | IP / Puerto | Protocolo | Rol |
| :--- | :--- | :--- | :--- |
| PLC Micro850 | `192.168.3.151:502` | Modbus TCP | Control de campo |
| UR3 Robot | `192.168.3.71:30002` | Modbus TCP + Socket | Planchado |
| Raspberry Pi cámara | `192.168.3.162:5000` | HTTP REST | Captura IA |
| Backend Render | `docker-planchaduria.onrender.com` | HTTPS REST | API nube |
| Firebase | Firebase Admin SDK | HTTPS | DB + Auth + Storage |
| ESP32 | COM3 / 115200 baud | Serial USB | Pistón + Torreta |

---

## Rol de cada componente en el CPS

### Raspberry Pi 3 — Orquestador central
Es el **cerebro del sistema**. Ejecuta [`rutina_maestra.py`](assets/files/rutina_maestra.py), que coordina todos los demás componentes. Hace polling a Firebase para detectar pedidos, controla el PLC por Modbus, envía scripts al UR3, comanda el ESP32 por serial, solicita fotos a la Raspberry cámara y ejecuta el modelo de IA localmente.

### PLC Allen Bradley Micro850 — Control de campo
Gestiona los **actuadores físicos y los sensores** del proceso: enciende/apaga el motor de la banda, lee el estado de los tres sensores (S1, S2, S3) y activa la plancha eléctrica (salida `000007`). Es la interfaz entre el mundo digital y el mundo físico de la línea de producción.

### UR3 — Robot colaborativo de planchado
Ejecuta las **trayectorias de planchado** sobre la prenda, con 7 waypoints calibrados por tipo de prenda. Recibe la instrucción de inicio vía señal Modbus y el script URScript por socket TCP. Es el actuador de mayor valor en el sistema.

### ESP32 — Control periférico
Controla la **torreta de señalización LED** (indica el estado del sistema visualmente en planta) y el **pistón eléctrico** que empuja la prenda planchada hacia el gancho de salida. Se comunica con la Raspberry Pi por serial USB.

### HMI — Interfaz local de operación
Panel táctil con Raspberry Pi 3 que muestra el estado del pedido en tiempo real (consultando Firebase) y lee el código QR del cliente mediante cámara integrada para validar el inicio del proceso.

### Firebase — Capa de datos y sincronización
Base de datos y plataforma de autenticación en la nube. Almacena pedidos (Firestore), estado del proceso en tiempo real (Realtime Database), fotografías de evidencia (Storage) y gestiona la autenticación de usuarios (Auth).

### Interfaz web — Punto de contacto con el cliente
Aplicación web en GitHub Pages que permite al cliente registrar su prenda, obtener el QR, consultar el estado del pedido y ver el historial. Se comunica directamente con Firebase mediante el SDK de JavaScript.

---

## Siguiente sección

[Diseño Mecánico](07-diseno-mecanico.md)

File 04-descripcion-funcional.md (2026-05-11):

---
layout: default
title: Descripción Funcional
nav_order: 5
---

# Descripción Funcional del Sistema

## Resumen del proceso

El sistema opera de forma **completamente autónoma** una vez que el usuario registra su prenda en la interfaz web y la coloca en la entrada de la banda transportadora. El proceso completo incluye 8 etapas secuenciales gestionadas por la rutina maestra en Raspberry Pi.

---

## Etapas del proceso

### Etapa 1 — Registro de prenda en la interfaz web
El cliente accede a la plataforma web ([luiscortesmunoz.github.io/Planchaduria](https://luiscortesmunoz.github.io/Planchaduria/)), crea su cuenta con autenticación Firebase, selecciona el tipo de prenda, material y cantidad. El sistema genera automáticamente un **código QR único** vinculado al pedido, almacenado en Firebase Realtime Database.

### Etapa 2 — Validación del QR en el HMI
El cliente presenta su código QR frente a la cámara integrada en el **HMI físico** (Raspberry Pi 3 con pantalla táctil). El sistema valida el ID del pedido contra la base de datos Firebase. Al confirmar la validación, el HMI muestra el estado del pedido y el proceso físico queda habilitado para iniciar.

### Etapa 3 — Detección de prenda (Sensor S1 — barrera infrarroja)
El cliente coloca la prenda en la entrada de la banda transportadora. El **sensor de barrera infrarroja (S1)** detecta la presencia de la prenda al interrumpir el haz de luz. La señal llega al PLC Micro850 (dirección `000004`), que activa el motor de la banda.

| Parámetro | Valor |
| :--- | :--- |
| Tipo de sensor | Barrera infrarroja |
| Dirección PLC | `000004` |
| Etapa interna | `ESPERA_SENSOR1` |

### Etapa 4 — Avance y captura fotográfica con IA
La banda avanza durante **45 segundos** hasta la estación de fotografía. Una **Raspberry Pi 3 con cámara** captura una imagen de la prenda y ejecuta el modelo [keras_model.h5](assets/files/keras_model.h5) (clasificador binario: Camisa / Playera, entrenado con Google Teachable Machine). El resultado y la fotografía se suben al backend en Render y quedan registrados en Firebase Storage como evidencia de recepción.

| Parámetro | Valor |
| :--- | :--- |
| Tiempo de avance previo | 45 segundos |
| Modelo IA | [keras_model.h5](assets/files/keras_model.h5) — Keras / TensorFlow |
| Clases detectadas | `Camisa` / `Playera` |
| Etapa interna | `FOTO` |

### Etapa 5 — Planchado automatizado con UR3 (Sensor S2)
La banda avanza hasta que el **sensor inductivo S2** (dirección `000005`) detecta la prenda en posición de planchado. El PLC envía la señal al UR3 vía **Modbus TCP**. El robot ejecuta la rutina correspondiente al tipo de prenda:

- [`camisa.script`](assets/files/camisa.script) — 7 waypoints para camisa de vestir
- [`playera.script`](assets/files/playera.script) — 7 waypoints para playera / camiseta

La plancha está montada en el efector final del UR3 mediante un agarrador impreso en **PLA**.

| Parámetro | Valor |
| :--- | :--- |
| Sensor de posición | Inductivo S2 — `000005` |
| Comunicación robot | Modbus TCP · IP `192.168.3.71` · Puerto `30002` |
| Señales | `RX74` (recepción) / `TX71` (transmisión) |
| Waypoints por rutina | 7 |
| Tiempo de rutina | ~15 segundos |
| Etapa interna | `UR3` |

### Etapa 6 — Salida y pistón (Sensor S3)
Finalizado el planchado, la banda avanza hasta el **sensor inductivo S3** (dirección `000006`), que marca el fin del proceso. El motor se detiene. El **ESP32** (conectado por serial a `COM3 / 115200 baud`) activa el **pistón eléctrico** durante 9 segundos, empujando la prenda hacia el gancho de salida para que el cliente la recoja.

| Parámetro | Valor |
| :--- | :--- |
| Sensor de salida | Inductivo S3 — `000006` |
| Actuador | Pistón eléctrico — ESP32 |
| Tiempo pistón extendido | 9 segundos |
| Avance final | 60 segundos |
| Etapa interna | `PISTON` → `AVANCE_FINAL_60S` |

### Etapa 7 — Finalización y trazabilidad en Firebase
El sistema actualiza el estado del pedido en Firebase como **"Listo para entrega"**. El dashboard web y el HMI reflejan la finalización. La fotografía de evidencia queda almacenada en Firebase Storage. El ciclo termina y el sistema retorna al estado de espera (`STOP`).

---

## Resumen de tiempos del proceso

| Etapa | Duración |
| :--- | :--- |
| Avance hasta estación de foto | 45 segundos |
| Captura y clasificación IA | ~3 segundos |
| Avance hasta posición UR3 | Variable (sensor S2) |
| Rutina de planchado UR3 | ~15 segundos |
| Avance hasta sensor S3 | Variable (sensor S3) |
| Extensión del pistón | 9 segundos |
| Avance final y paro | 60 segundos |

---

## Siguiente sección

[Algoritmo de Funcionamiento](05-algoritmo.md)

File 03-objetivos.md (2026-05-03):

---
layout: default
title: Objetivos
nav_order: 4
---

# Objetivos del Proyecto

## Objetivo General

Diseñar e implementar un sistema ciberfísico capaz de **automatizar el proceso de planchado de prendas textiles** en un entorno industrial, integrando robótica colaborativa (UR3), control PLC (Micro850), visión artificial por inteligencia artificial (Keras/TensorFlow) e infraestructura IoT en la nube (Firebase/Render), aplicando los conocimientos y herramientas adquiridos a lo largo de la carrera de Ingeniería Mecatrónica.

---

## Objetivos Específicos

### 1. Automatización robótica con UR3
Programar el robot colaborativo UR3 para ejecutar trayectorias de planchado diferenciadas según el tipo de prenda detectada (camisa o playera), utilizando URScript con 7 waypoints calibrados por rutina y comunicación Modbus TCP con el sistema de control.

### 2. Clasificación automática de prendas por IA
Implementar un modelo de visión artificial entrenado con Keras/TensorFlow (`keras_model.h5`) capaz de clasificar automáticamente el tipo de prenda mediante fotografía capturada por Raspberry Pi, con retroalimentación al sistema para seleccionar la rutina correcta del robot.

### 3. Control industrial mediante PLC Micro850
Programar el PLC Allen Bradley Micro850 para gestionar la lógica de control del motor de la banda transportadora, los tres sensores del proceso (barrera IR + 2 inductivos) y los actuadores de campo (motor, plancha), comunicándose vía Modbus TCP con la Raspberry Pi orquestadora.

### 4. Interfaz web con trazabilidad completa
Desarrollar una plataforma web responsive hospedada en GitHub Pages que permita al usuario registrar su prenda, obtener un código QR de seguimiento y monitorear el estado del proceso en tiempo real, con historial almacenado en Firebase y fotografía de evidencia de cada prenda procesada.

### 5. HMI de monitoreo industrial
Implementar un panel HMI físico sobre Raspberry Pi 3 con pantalla táctil que muestre el estado operativo del sistema, lea el código QR del cliente mediante cámara integrada y permita la supervisión local del proceso de planchado en tiempo real.

### 6. Arquitectura ciberfísica completa e integrada
Integrar todos los componentes del sistema (UR3, PLC Micro850, Raspberry Pi, ESP32, Firebase, HMI, interfaz web) en una arquitectura ciberfísica coherente con comunicación bidireccional, gestión de estados por etapas y manejo de errores robusto.

---

## Siguiente sección

[Descripción Funcional del Sistema](04-descripcion-funcional.md)

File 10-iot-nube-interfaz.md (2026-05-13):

---
layout: default
title: IoT / Nube / Interfaz Web
nav_order: 11
---

# IoT / Nube / Interfaz Web

## Arquitectura de la capa de conectividad

La capa IoT del sistema integra tres servicios en la nube que operan de forma coordinada:

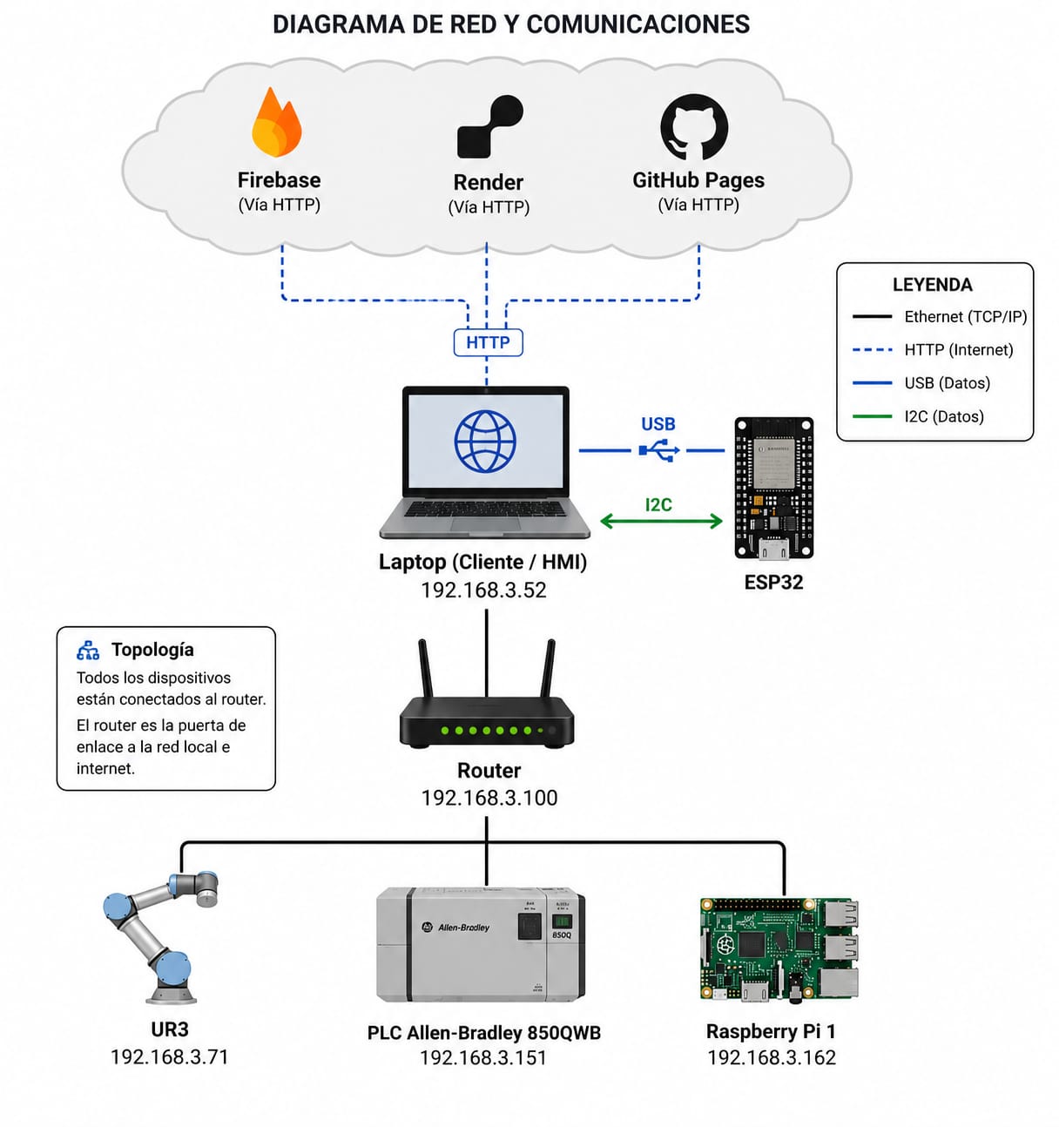
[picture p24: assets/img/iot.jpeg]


---

## Firebase — Base de datos y autenticación

Firebase es el **eje central de datos** del sistema. Gestiona cuatro servicios:

| Servicio Firebase | Uso en el proyecto |
| :--- | :--- |
| **Firebase Auth** | Autenticación de usuarios con email + verificación por código |
| **Firestore** | Almacenamiento de pedidos, clientes y estado del sistema |
| **Realtime Database** | Estado en tiempo real del pedido activo (para HMI y dashboard) |
| **Firebase Storage** | Fotografías de evidencia de cada prenda procesada |

### Estructura de datos en Realtime Database

```json
{
  "estado_actual": {
      "usuario_actual": "229",
          "cantidad": 1,
              "activo": true,
                  "estado": "En proceso",
                      "current_order_id": "abc123",
                          "updated_at": "2026-04-27T17:20:33"
                            }
                            }
```

---

### Registro de usuarios en Cloud Firestore

Vista de Firestore

**Figura 1.** Vista de la colección `usuarios` en Cloud Firestore, donde se almacenan los datos principales de cada usuario registrado.

---

### Almacenamiento de fotografías en Firebase Storage

fotos de Firestore

**Figura 2.** Almacenamiento de fotografías de evidencia en Firebase Storage.

## Backend Flask — Render (Docker)

El backend está construido con **Flask** y desplegado en **Render** como contenedor Docker. Actúa como intermediario entre la interfaz web, Firebase y la Raspberry Pi.

### Dependencias (`requirements.txt`)
[`requirements.txt`](assets/files/requirements.txt)
```
Flask==3.0.3
flask-cors==4.0.1
firebase-admin==6.5.0
gunicorn==22.0.0
Werkzeug==3.0.3
requests==2.32.3
```

### Endpoints disponibles

| Endpoint | Método | Función |
| :--- | :--- | :--- |
| `GET /estado` | GET | Estado actual del sistema y pedido activo |
| `POST /activar_plc` | POST | Activa el proceso físico (inicio del ciclo) |
| `POST /desactivar_plc` | POST | Detiene el proceso físico |
| `POST /set_cantidad` | POST | Actualiza la cantidad de prendas del pedido |
| `POST /subir_foto` | POST | Sube fotografía de evidencia a Firebase Storage |
| `GET /fotos` | GET | Lista las fotografías del pedido actual |
| `GET /historial` | GET | Historial completo de pedidos procesados |

### URL del backend en producción

```
https://docker-planchaduria.onrender.com
```

{: .note }
El plan gratuito de Render suspende el contenedor tras 15 minutos de inactividad. La rutina maestra implementa reintentos automáticos para el arranque en frío.

---

## Interfaz Web — GitHub Pages

La interfaz web es una **Single Page Application** (SPA) hospedada en GitHub Pages, que se comunica directamente con Firebase mediante el SDK de JavaScript.

**URL:** [luiscortesmunoz.github.io/Planchaduria](https://luiscortesmunoz.github.io/Planchaduria/)

### Funcionalidades para el cliente

| Función | Descripción |
| :--- | :--- |
| Registro / Login | Autenticación Firebase con verificación por correo |
| Registrar prenda | Selección de tipo, material y cantidad |
| Generación de QR | QR único vinculado al ID del pedido |
| Estado en tiempo real | Consulta del estado actual del pedido |
| Historial | Listado de todas las prendas procesadas |
| Evidencia fotográfica | Foto de la prenda tomada durante el proceso |

### Panel de administrador

La interfaz incluye un **panel de administrador** protegido por autenticación que permite:

- Ver el dashboard general con totales (pendientes, en proceso, listos, entregados)
- Gestionar pedidos (crear, editar, actualizar estado, eliminar)
- Ver el directorio de clientes registrados
- Cambiar manualmente el estado de cualquier pedido

---

## Dashboard industrial local

El archivo [`dashboard_server.py`](https://github.com/Marthavlds1/DocumentacionCiberfisicosPF/blob/53bd11cb4e1ae3bd55e17dc11fb92a7b8c506ee0/dashboard_server.py), sirve un **panel de monitoreo** accesible en la red local del laboratorio (puerto `5050`), que muestra en tiempo real:

- Etapa actual del proceso (`ESPERA_SENSOR1`, `UR3`, `PISTON`, etc.)
- Estado de los tres sensores (S1, S2, S3)
- Estado del motor y la plancha
- Tipo de prenda detectada por IA y nivel de confianza
- Logs de la rutina maestra en tiempo real (vía SSE)
- Información del pedido activo (ID, usuario, cantidad, tipo de prenda)

---

---

## Recursos asociados (Sección 10)

### Planchaduria-main  
Código fuente de la **interfaz web del cliente** (SPA en GitHub Pages + Firebase).  
Descarga: [Planchaduria-main](assets/files/Planchaduria-main.zip)

---

### Docker_Planchaduria  
Backend desarrollado en Flask y desplegado en Render como contenedor Docker (API REST del sistema).  
Descarga: [Docker_Planchaduria](assets/files/Docker_Planchaduria-main.zip)

---

Ambos repositorios forman parte de la **Sección 10 — IoT / Nube / Interfaz Web**, ya que implementan la comunicación entre el cliente, la nube y el sistema físico.

## Siguiente sección

[Simulación y Modelado](11-simulacion.md)

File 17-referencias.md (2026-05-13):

---
layout: default
title: Referencias
nav_order: 19
---

# Referencias

Las siguientes fuentes fueron consultadas durante el diseño, implementación y documentación del proyecto, presentadas en formato **IEEE**.

---

## Robótica colaborativa

[1] Universal Robots, *UR3 User Manual*, versión 5.x. Odense, Dinamarca: Universal Robots A/S, 2023. [En línea]. Disponible en: <https://www.universal-robots.com/manuals>

[2] Universal Robots, *URScript Programming Language*, versión 5.x. Odense, Dinamarca: Universal Robots A/S, 2023. [En línea]. Disponible en: <https://www.universal-robots.com/manuals>

## Control industrial

[3] Rockwell Automation, *Micro850 Programmable Controller User Manual*, Publication 2080-UM002. Milwaukee, WI: Rockwell Automation, 2023.

[4] Rockwell Automation, *Connected Components Workbench Software User Manual*, Publication 9324-UM001. Milwaukee, WI: Rockwell Automation, 2022.

## Protocolos de comunicación

[5] Modbus Organization, *Modbus Application Protocol Specification V1.1b3*. [En línea]. Disponible en: <https://modbus.org/docs/Modbus_Application_Protocol_V1_1b3.pdf>, 2012.

[6] J. Goerge, *Mastering Python for Networking and Security*. Birmingham, UK: Packt Publishing, 2018. (Capítulo sobre pymodbus)

## Inteligencia artificial y visión por computadora

[7] F. Chollet, *Deep Learning with Python*, 2nd ed. Shelter Island, NY: Manning Publications, 2021.

[8] Google Creative Lab, *Teachable Machine — Train a computer to recognize your own images, sounds, and poses*. [En línea]. Disponible en: <https://teachablemachine.withgoogle.com/>, 2024.

[9] TensorFlow Team, *TensorFlow Documentation*. [En línea]. Disponible en: <https://www.tensorflow.org/api_docs>, 2024.

## Sistemas ciberfísicos e IoT

[10] E. A. Lee y S. A. Seshia, *Introduction to Embedded Systems: A Cyber-Physical Systems Approach*, 2nd ed. Cambridge, MA: MIT Press, 2017.

[11] Google, *Firebase Documentation — Realtime Database*. [En línea]. Disponible en: <https://firebase.google.com/docs/database>, 2024.

[12] Google, *Firebase Documentation — Authentication*. [En línea]. Disponible en: <https://firebase.google.com/docs/auth>, 2024.

## Plataformas de desarrollo

[13] Raspberry Pi Foundation, *Raspberry Pi Documentation*. [En línea]. Disponible en: <https://www.raspberrypi.com/documentation/>, 2024.

[14] Espressif Systems, *ESP32 Technical Reference Manual*. Shanghai, China: Espressif Systems, 2023. [En línea]. Disponible en: <https://www.espressif.com/en/support/documents/technical-documents>

[15] Pallets Projects, *Flask Documentation*, versión 3.0. [En línea]. Disponible en: <https://flask.palletsprojects.com/>, 2024.

[16] Docker Inc., *Docker Documentation*. [En línea]. Disponible en: <https://docs.docker.com/>, 2024.

---

[Volver al inicio](index.md)

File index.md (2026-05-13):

---
layout: default
title: Inicio
nav_order: 1
---

# Planchado Express — Sistemas Ciberfísicos

Bienvenido a la documentación técnica del proyecto **Planchado Express**, desarrollado como parte de la asignatura de **Sistemas Ciberfísicos** en la Universidad Iberoamericana, Primavera 2026.



---

## Identidad del Proyecto

| Campo | Descripción |
| :--- | :--- |
| **Proyecto** | Planchado Express |
| **Materia** | Sistemas Ciberfísicos |
| **Institución** | Universidad Iberoamericana (IBERO) |
| **Programa** | Ingeniería Mecatrónica y Sistemas Ciberfísicos |
| **Semestre** | Noveno semestre |
| **Periodo** | Primavera 2026 |

## Cuerpo Docente

- **Mtro. Joel Arango Ramírez.**
- **Dr. Huber Girón Nieto.**

## Integrantes del Equipo

| Integrante | Programa |
| :--- | :--- |
| Luis Cortés Muñoz | Ingeniería Mecatrónica |
| Emmanuel Iturbide Rebolledo | Ingeniería Mecatrónica |
| Alexander Moncada Rivas | Ingeniería Mecatrónica |
| Martha Valdés Cruz | Ingeniería Mecatrónica |
| Renata Badillo Cabrera | Ingeniería Mecatrónica |
| Camila Sánchez Guevara | Ingeniería Mecatrónica |

---

## Descripción General del Sistema

**Planchado Express** es un sistema ciberfísico integrado que automatiza el proceso de planchado de prendas textiles en un entorno industrial. El usuario únicamente registra su prenda en la interfaz web y la coloca en la entrada de la banda transportadora; a partir de ese momento, el sistema opera de forma completamente autónoma.

El sistema integra:

- **Robot colaborativo UR3** — ejecuta las trayectorias de planchado
- **PLC Allen Bradley Micro850** — controla la banda, sensores y actuadores
- **Raspberry Pi 3** — orquesta el proceso completo y clasifica prendas con IA
- **ESP32** — controla la torreta de señalización y el pistón de salida
- **HMI** — panel táctil con lector QR para validación de pedidos
- **Firebase + Render** — nube para trazabilidad y gestión de pedidos
- **Interfaz web** — registro y monitoreo desde cualquier dispositivo

---

## Contenido de la Documentación

- [01. Contexto General](01-contexto.md)
- [02. Problema de Ingeniería](02-problema.md)
- [03. Objetivos](03-objetivos.md)
- [04. Descripción Funcional](04-descripcion-funcional.md)
- [05. Algoritmo de Funcionamiento](05-algoritmo.md)
- [06. Arquitectura Ciberfísica](06-arquitectura.md)
- [07. Diseño Mecánico](07-diseno-mecanico.md)
- [08. Diseño Electrónico](08-diseno-electronico.md)
- [09. Control y Programación](09-control-programacion.md)
- [10. IoT / Nube / Interfaz Web](10-iot-nube-interfaz.md)
- [11. Simulación y Modelado](11-simulacion.md)
- [12. Materiales y Costos](12-materiales-costos.md)
- [13. Metodología de Desarrollo](13-metodologia.md)
- [14. Resultados](14-resultados.md)
- [15. Problemas Encontrados](15-problemas.md)
- [16. Evidencia Visual](16-evidencia.md)
- [17. Mejoras Futuras](18-Mejoras-Futuras.md)
- [18. Referencias](17-referencias.md)

---

© 2026 — Universidad Iberoamericana · Sistemas Ciberfísicos

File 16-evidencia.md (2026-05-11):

---
layout: default
title: Evidencia Visual
nav_order: 17
---

# Evidencia Visual

## Fotografías del sistema

{: .note }
Fotografías del sistema físico. Coloca tus imágenes en la carpeta `assets/img/evidencia/` y reemplaza los nombres de archivo en los ejemplos de abajo.

### Sistema completo — Vista general



### Robot UR3 con efector y plancha



### Tablero PLC Micro850



### HMI con lector QR



### Banda transportadora y sensores



---

## Interfaz web — Capturas de pantalla

La interfaz web está disponible en vivo en:

[luiscortesmunoz.github.io/Planchaduria](https://luiscortesmunoz.github.io/Planchaduria/){: .btn .btn-red }

### Pantalla principal — Inicio de sesión


### Registro de prenda y generación de QR



### Video Funcionamiento
<video controls width="720">
  <source src="{{ '/assets/img/pagina.mp4' | relative_url }}" type="video/mp4">
  Tu navegador no soporta el formato de video.
</video>
---

## Prendas procesadas — Evidencia fotográfica IA

Las siguientes fotografías fueron capturadas automáticamente durante las pruebas del 27–28 de abril de 2026 y almacenadas en [Firebase Storage](assets/files/fotos_pc):

| Archivo | Usuario | Fecha | Clasificación IA |
| :--- | :--- | :--- | :--- |
| `usuario_229_foto_1_20260427_172033.jpg` | 229 | 27 Abr · 17:20 | — |
| `usuario_230_foto_1_20260427_190505.jpg` | 230 | 27 Abr · 19:05 | — |
| `usuario_231_foto_1_20260427_191223.jpg` | 231 | 27 Abr · 19:12 | — |
| `usuario_233_foto_1_20260427_203505.jpg` | 233 | 27 Abr · 20:35 | — |
| `usuario_234_foto_1_20260427_203911.jpg` | 234 | 27 Abr · 20:39 | — |
| `usuario_235_foto_1_20260427_204239.jpg` | 235 | 27 Abr · 20:42 | — |
| `usuario_236_foto_1_20260427_205636.jpg` | 236 | 27 Abr · 20:56 | — |
| `usuario_237_foto_1_20260427_211726.jpg` | 237 | 28 Abr · 21:17 | — |
| `usuario_238_foto_1_20260427_212537.jpg` | 238 | 28 Abr · 21:25 | — |
| `usuario_239_foto_1_20260427_213958.jpg` | 239 | 28 Abr · 21:39 | — |

---

## Video de demostración

<video controls width="720">
  <source src="{{ '/assets/img/videofinal.mp4' | relative_url }}" type="video/mp4">
  Tu navegador no soporta el formato de video.
</video>

---

## Siguiente sección

[Referencias](17-referencias.md)

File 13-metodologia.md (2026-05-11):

---
layout: default
title: Metodología de Desarrollo
nav_order: 14
---

# Metodología de Desarrollo

## Enfoque metodológico

El proyecto siguió una **metodología iterativa por capas**, desarrollando e integrando cada subsistema de forma incremental. En lugar de intentar construir el sistema completo de una vez, el equipo validó cada capa antes de integrarla con las demás.

---

## Etapas de desarrollo

### Etapa 1 — Definición del sistema (Enero 2026)
- Identificación del problema y selección del caso de uso (planchado industrial)
- Selección de componentes disponibles en el laboratorio
- Diseño de la arquitectura ciberfísica y definición del flujo de proceso
- Investigación de protocolos de comunicación (Modbus TCP, Serial USB, Firebase)

### Etapa 2 — Construcción de la estructura física (Febrero 2026)
- Ensamble de la banda transportadora
- Instalación de los tres sensores en posiciones calibradas
- Montaje del UR3 y fabricación del efector PLA mediante impresión 3D
- Conexión del tablero PLC Micro850 con sus entradas y salidas digitales

### Etapa 3 — Programación del PLC y calibración del UR3 (Feb–Mar 2026)
- Desarrollo de la lógica de control en Connected Components Workbench (CCW)
- Programación y calibración de los 7 waypoints de cada rutina URScript en PolyScope
- Validación de las trayectorias sin carga antes de montar la plancha

### Etapa 4 — Backend, Firebase e interfaz web (Marzo 2026)
- Configuración de Firebase (Auth, Firestore, Realtime Database, Storage)
- Implementación del backend Flask (Docker / Render)
- Desarrollo de la interfaz web en GitHub Pages con registro de pedidos, QR y panel de administrador

### Etapa 5 — Modelo IA y sistema de cámara (Mar–Abr 2026)
- Recopilación del dataset de prendas (camisas y playeras)
- Entrenamiento del clasificador con Google Teachable Machine
- Exportación a [`keras_model.h5`](assets/files/keras_model.h5) e integración con la Raspberry Pi de cámara
- Validación de la clasificación con imágenes de prueba

### Etapa 6 — Integración completa y rutina maestra (Abril 2026)
- Desarrollo de [`rutina_maestra.py`](assets/files/rutina_maestra.py) como orquestador central
- Integración de todos los subsistemas en el ciclo completo [`dashboard_server.py`](assets/files/dashboard_server.py)
- Pruebas de ciclo completo con prendas reales

### Etapa 7 — Pruebas, ajustes y documentación (Abr–May 2026)
- Ajuste de tiempos del proceso (45 seg foto, 15 seg UR3, 9 seg pistón, 60 seg final)
- Implementación del filtro de debounce para sensores
- Elaboración de la documentación técnica en GitHub Pages

---

## División del trabajo

| Área | Responsabilidad |
| :--- | :--- |
| Robótica (UR3) | Programación y calibración de trayectorias URScript |
| Control (PLC) | Lógica de campo en CCW, Modbus TCP |
| Inteligencia Artificial | Entrenamiento de modelo, integración con Raspberry Pi |
| Backend / Nube | Flask API, Firebase, Docker, Render |
| Interfaz web | GitHub Pages, autenticación, QR, panel admin |
| Integración |[`rutina_maestra.py`](assets/files/rutina_maestra.py), arquitectura ciberfísica completa |

---

## Siguiente sección

[Resultados](14-resultados.md)

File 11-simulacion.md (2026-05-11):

---
layout: default
title: Simulación y Modelado
nav_order: 12
---

# Simulación y Modelado

## Estrategia de validación digital

El proyecto utilizó cuatro herramientas de simulación y validación antes de la implementación física:

---

## 1. Programación del UR3 en PolyScope

Las trayectorias de planchado fueron programadas y validadas en el **entorno de programación PolyScope** del propio UR3. Este entorno permite:

- Definir waypoints de forma interactiva moviendo el robot manualmente.
- Verificar alcance articular y detectar singularidades.
- Simular la trayectoria completa en modo "fantasma" antes de ejecutarla físicamente.
- Exportar el programa como script URScript ( [`camisa.script`](assets/files/camisa.script)/ [`playera.script`](assets/files/playera.script)).

Las rutinas fueron validadas con la plancha montada en el efector para verificar que no había colisiones con la estructura de la banda.

---

## 2. Entrenamiento del modelo IA — Google Teachable Machine

El clasificador de prendas fue entrenado con **Google Teachable Machine**:

1. Se recolectaron imágenes de camisas y playeras en condiciones similares a las del sistema real (iluminación del laboratorio, ángulo de la cámara).
2. Se entrenó el modelo con las dos clases: `Camisa` y `Playera`.
3. El modelo exportado en formato Keras (`.h5`) fue validado con un conjunto de imágenes de prueba antes de su integración.

| Parámetro del modelo | Valor |
| :--- | :--- |
| Archivo | [`keras_model.h5`](assets/files/keras_model.h5) |
| Etiquetas | `labels.txt` → `0 Camisa`, `1 Playera` |
| Tamaño de entrada | 224 × 224 px |
| Normalización | `/127.5 - 1` (rango [-1, 1]) |
| Framework | TF-Keras / TensorFlow |

---

## 3. Lógica PLC en Connected Components Workbench

La lógica de control del PLC Micro850 fue desarrollada y simulada en **Connected Components Workbench (CCW)** antes de descargarse al hardware. CCW permite:

- Simular el comportamiento de las entradas y salidas digitales.
- Verificar la secuencia de activación del motor y respuesta a sensores.
- Depurar la lógica Ladder antes de la integración con Modbus.

---

## 4. Pruebas de integración con dashboard_server.py

El [ `dashboard_server.py`](assets/files/dashboard_server.py) permitió realizar pruebas de la [`rutina_maestra.py`](assets/files/rutina_maestra.py) monitoreando el flujo completo de estados sin necesidad de tener todo el hardware conectado simultáneamente. El sistema de SSE y parseo de logs facilitó la detección temprana de errores de integración.

---

## Siguiente sección

[Materiales y Costos](12-materiales-costos.md)

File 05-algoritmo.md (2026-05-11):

---
layout: default
title: Algoritmo de Funcionamiento
nav_order: 6
---

# Algoritmo de Funcionamiento

## Lógica de control por etapas

El sistema utiliza una **máquina de estados explícita** implementada en [`rutina_maestra.py`](assets/files/rutina_maestra.py). Cada etapa se nombra con una clave única y el estado se actualiza mediante la función `cambiar_etapa()`, que imprime el estado para que el dashboard pueda interpretarlo en tiempo real.

```python
def cambiar_etapa(nueva_etapa: str):
    global etapa_actual
    etapa_actual = nueva_etapa
    print(f"[ESTADO] Etapa actual -> {etapa_actual}")
```

---

## Estados del sistema

| Clave de etapa | Descripción |
| :--- | :--- |
| `STOP` | Sistema en reposo, esperando pedido |
| `ESPERA_SENSOR1` | Esperando detección de prenda en entrada (barrera IR) |
| `AVANCE_45S_ANTES_FOTO` | Banda avanzando 45 seg hacia estación de fotografía |
| `FOTO` | Captura fotográfica y clasificación IA en curso |
| `AVANCE_A_SENSOR2` | Banda avanzando hacia posición de planchado (UR3) |
| `UR3` | Robot ejecutando rutina de planchado |
| `AVANCE_A_SENSOR3` | Banda avanzando hacia estación de salida |
| `PISTON` | Pistón eléctrico activo — empujando prenda al gancho |
| `AVANCE_FINAL_60S` | Avance final de 60 segundos antes del STOP |

---

## Diagrama de flujo
A continuación se expone el diagrama de flujo, donde se incluye todo el proceso del funcionamiento de la planchaduria.
<iframe src="{{ site.baseurl }}/assets/files/Dibujo.pdf" width="100%" height="700"></iframe>

## Manejo de errores

El sistema implementa mecanismos de robustez ante fallas:

- **Debounce de sensores:** se requieren 3 lecturas consecutivas en 50 ms para validar el estado de un sensor, filtrando ruido eléctrico y rebotes mecánicos.
- **Reintentos de fotografía:** hasta 3 intentos con 2 segundos de espera entre reintentos si la cámara Raspberry no responde.
- **Watchdog del UR3:** `rtde_set_watchdog("speed_slider_mask", 10.0, "ignore")` evita bloqueos por pérdida de conexión.
- **Gestión de errores en loop:** cualquier excepción en el loop principal es capturada, registrada y reportada al dashboard sin detener el sistema.

---

## Siguiente sección

[Arquitectura Ciberfísica](06-arquitectura.md)

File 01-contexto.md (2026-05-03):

---
layout: default
title: Contexto General
nav_order: 2
---

# Contexto General del Proyecto

## Entorno de aplicación

**Planchado Express** se ubica en el contexto de la industria de **planchadurías comerciales**, donde el proceso de planchado de prendas representa una actividad central del negocio. Este tipo de establecimientos atiende volúmenes altos de prendas diariamente, lo que convierte la automatización en una palanca de mejora operativa significativa.

El proyecto busca demostrar que los principios de los **sistemas ciberfísicos** — la integración coherente de componentes físicos con capas de software, control y conectividad — pueden aplicarse con éxito a procesos industriales de uso cotidiano.

---

## ¿Qué es Planchado Express?

Planchado Express es un **sistema ciberfísico integrado** que automatiza el proceso completo de planchado de prendas textiles. El cliente únicamente:

1. Registra su prenda en la interfaz web y obtiene un código QR.
2. Presenta su QR en el HMI y coloca la prenda en la entrada de la banda.

A partir de ese momento, el sistema opera de forma **completamente autónoma**: la prenda es transportada, fotografiada, clasificada por inteligencia artificial, planchada por el robot UR3 y entregada mediante un pistón de salida, sin intervención humana adicional.

---

## Origen del proyecto

La idea surgió en el aula durante la asignatura de Sistemas Ciberfísicos, como respuesta al reto de **automatizar un proceso de la vida diaria** utilizando las herramientas aprendidas a lo largo de la carrera de Ingeniería Mecatrónica.

El planchado fue elegido por su viabilidad técnica dentro del laboratorio y por representar un proceso con pasos secuenciales claros, susceptible de ser orquestado mediante un sistema de control y comunicación distribuida.

---

## Tipo de prendas

El prototipo está enfocado en el tratamiento de **prendas de tela plana**:

- Camisas de vestir
- Playeras / camisetas

La clasificación entre ambos tipos se realiza automáticamente mediante un modelo de **inteligencia artificial** (Keras/TensorFlow) que analiza la fotografía de la prenda antes de seleccionar la trayectoria de planchado del robot.

---

## Alcance del proyecto

El desarrollo corresponde a un **prototipo funcional** orientado a:

- Demostrar la viabilidad técnica de la integración ciberfísica completa.
- Validar la comunicación entre todos los subsistemas (PLC, robot, IA, nube, HMI).
- Evidenciar el uso de protocolos industriales (Modbus TCP) y de IoT (Firebase, REST).

No se busca aún un producto comercial terminado, sino una solución experimental capaz de validar el concepto de automatización del planchado en entorno académico-industrial.

---

## Siguiente sección

[Problema de Ingeniería](02-problema.md)

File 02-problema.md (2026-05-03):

---
layout: default
title: Problema de Ingeniería
nav_order: 3
---

# Problema de Ingeniería

## Planteamiento

Las planchadurías industriales dependen en su totalidad del **trabajo manual humano** para el proceso de planchado. Esta dependencia genera ineficiencias operativas, riesgos ergonómicos para el personal, inconsistencias en la calidad del servicio y un costo operativo elevado por mano de obra especializada.

> **Pregunta de ingeniería:** ¿Es posible automatizar el proceso completo de planchado de prendas textiles mediante un sistema ciberfísico que integre robótica colaborativa, control PLC, visión artificial e infraestructura IoT, eliminando la necesidad de un operario especializado durante la ejecución del proceso?

---

## Situación actual sin automatización

En una planchaduría comercial sin automatización, el proceso típico es el siguiente:

1. El cliente entrega la prenda en mostrador.
2. Un operario toma la prenda y la coloca manualmente en la mesa de planchado.
3. El operario selecciona la temperatura adecuada según el tipo de tela.
4. Plancha la prenda de forma manual, recorriendo toda su superficie.
5. Dobla o cuelga la prenda y la devuelve al cliente.

Este proceso requiere **atención constante del operario** durante todo el ciclo, impidiendo que realice otras tareas en paralelo.

---

## Limitantes identificadas

| Problema | Impacto |
| :--- | :--- |
| **Lentitud del proceso** | El operario dedica atención exclusiva a una prenda, limitando el volumen de servicio |
| **Requerimiento de operario especializado** | Incrementa el costo de mano de obra y genera dependencia de personal calificado |
| **Riesgo de quemaduras** | Manipulación directa de plancha caliente — riesgo laboral constante |
| **Fatiga física** | El esfuerzo repetitivo afecta la calidad del trabajo y la salud del operario |
| **Inconsistencia en calidad** | El resultado varía según el estado físico y la experiencia del operario |

---

## Justificación de la automatización

La automatización del proceso de planchado permite:

- **Liberar al operario** para tareas de mayor valor agregado (atención al cliente, control de calidad, gestión de pedidos).
- **Estandarizar la calidad** del planchado mediante trayectorias calibradas del robot.
- **Eliminar el riesgo** de quemaduras al operario durante el proceso.
- **Escalar el volumen** de servicio sin incremento proporcional en mano de obra.
- **Generar trazabilidad** completa de cada prenda procesada mediante fotografía y registro en la nube.

---

## Siguiente sección

[Objetivos](03-objetivos.md)

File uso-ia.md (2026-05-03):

---
layout: default
title: Uso de IA en la documentación
nav_exclude: true
---

# Sobre la elaboración de esta documentación

Esta documentación técnica se desarrolló combinando la **experiencia y el trabajo del equipo** con el apoyo de herramientas de **inteligencia artificial generativa** (Claude de Anthropic) para estructurar, redactar y organizar el contenido técnico.

Todo el material ha sido **revisado, validado y complementado por los integrantes del equipo** antes de su publicación. Los datos técnicos, IPs, protocolos, tiempos de proceso, scripts y arquitectura reflejan el sistema real implementado en el laboratorio de la Universidad Iberoamericana durante el semestre Primavera 2026.

Cualquier error, omisión o interpretación es responsabilidad exclusiva del equipo autor.

---

© 2026 — Universidad Iberoamericana · Sistemas Ciberfísicos · Primavera 2026

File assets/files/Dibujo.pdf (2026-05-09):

Inicio del proceso en la página web; ¿El usuario tiene una cuenta registrada?; Crear cuenta de usuario; Iniciar sesión; Página principal del sistema; ¿Desea registrar una nueva prenda?; Registrar datos de la prenda; ¿Confirmar creación del pedido?; Generar código QR del pedido Si; Registrar pedido en la estructura del HMI; ¿La prenda ya se encuentra en el mecanismo?; Continuar proceso: Esperar 3 segundos para estabilización; Avanzar el mecanismo durante 1 minuto; Detener el mecanismo; Capturar fotografía de la prenda; Guardar fotografía en la base de datos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

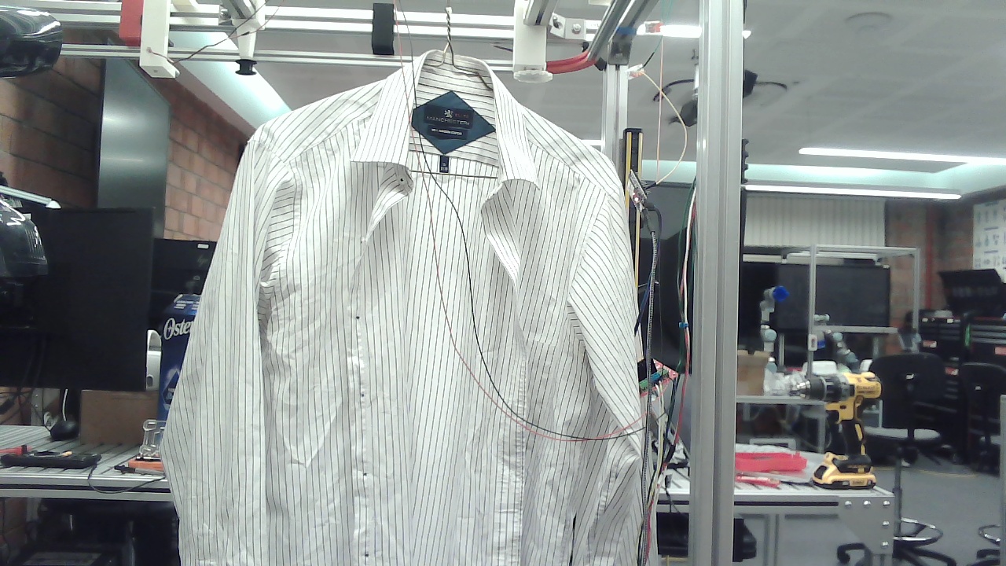
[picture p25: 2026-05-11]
assets/files/fotos_pc/usuario_235_foto_1_20260427_204239.jpg

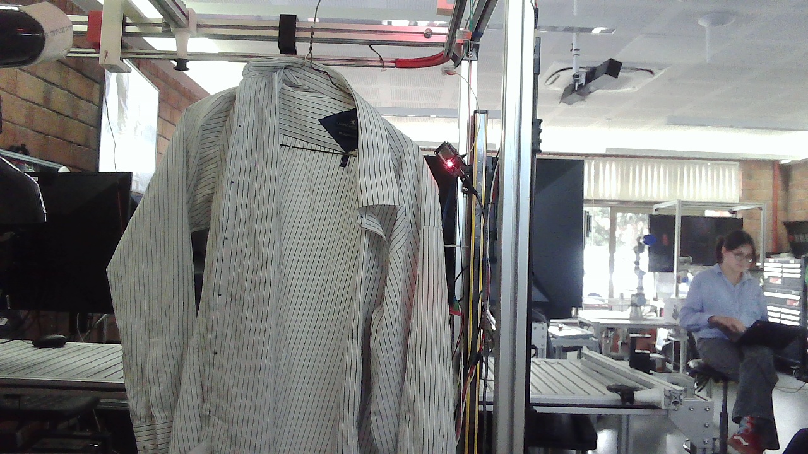
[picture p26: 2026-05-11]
assets/files/fotos_pc/usuario_230_foto_1_20260427_190505.jpg

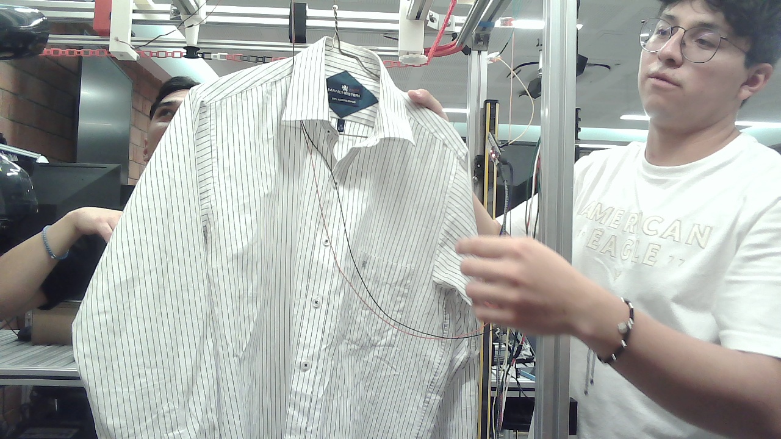
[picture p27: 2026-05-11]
assets/files/fotos_pc/usuario_237_foto_1_20260427_211726.jpg

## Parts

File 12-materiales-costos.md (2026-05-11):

---
layout: default
title: Materiales y Costos
nav_order: 13
---

# Materiales y Costos

Los materiales listados fueron utilizados en el proyecto.Los precios fueron investigados en Amazon México, MercadoLibre y distribuidores nacionales en 2026.

---

## Control industrial y robótica

| # | Material | Especificación | Cantidad | Precio unitario (MXN) | Total (MXN) |
| :---: | :--- | :--- | :---: | ---: | ---: |
| 1 | PLC Allen Bradley Micro850 | Tablero completo — Modbus TCP `192.168.3.151` | 1 | Laboratorio IBERO | — |
| 2 | Robot colaborativo UR3 | Universal Robots UR3, 6 DOF, TCP `[0,0,0.077]` | 1 | Laboratorio IBERO | — |
| 3 | HMI — Pantalla táctil | IPS DSI 7" sobre Raspberry Pi 3 | 1 | $1,500 | $1,500 |

## Cómputo y microcontroladores

| # | Material | Especificación | Cantidad | Precio unitario (MXN) | Total (MXN) |
| :---: | :--- | :--- | :---: | ---: | ---: |
| 4 | Raspberry Pi 4 Modelo B | 4 GB RAM — orquestador principal `rutina_maestra.py` | 1 | $2,741 | $2,741 |
| 5 | Raspberry Pi 3 Modelo B+ | HMI + lector QR | 1 | $1,800 | $1,800 |
| 6 | ESP32-S3 XIAO Seeed Studio | WiFi + BLE 5.0 — Serial COM3 / 115200 baud | 1 | $320 | $320 |

## Sensores

| # | Material | Especificación | Cantidad | Precio unitario (MXN) | Total (MXN) |
| :---: | :--- | :--- | :---: | ---: | ---: |
| 7 | Sensor de cortina IR | 12 Beams BEM1240-C-440NB — S1 entrada de banda | 1 | $650 | $650 |
| 8 | Sensor inductivo NPN NO | LJ12A3-4-Z/BX M12 6–36V — S2 posición UR3 | 1 | $120 | $120 |
| 9 | Sensor inductivo NPN NO | LJ12A3-4-Z/BX M12 6–36V — S3 posición salida | 1 | $120 | $120 |

## Actuadores

| # | Material | Especificación | Cantidad | Precio unitario (MXN) | Total (MXN) |
| :---: | :--- | :--- | :---: | ---: | ---: |
| 10 | Motor paso a paso Nema 17 | 17HS4401, 4 kg/cm, 1.7A bipolar | 1 | $350 | $350 |
| 11 | Driver TB6600 | 9–42V 4A — control motor Nema 17 | 1 | Incluido | — |
| 12 | Pistón eléctrico | Actuador lineal eléctrico mini — control ESP32 | 1 | Por cotizar | — |
| 13 | Plancha de vapor | T-fal vertical 700–750 g — efector UR3 | 1 | $1,100 | $1,100 |
| 14 | Tiras LED NeoPixel WS2812 | Stick 8×5050 RGB — torreta manual | 6 | $180 | $1,080 |

## Estructura mecánica

| # | Material | Especificación | Cantidad | Precio unitario (MXN) | Total (MXN) |
| :---: | :--- | :--- | :---: | ---: | ---: |
| 15 | Perfil aluminio V-Slot 40×40 mm | Estructura principal | Por cotizar | — | — |
| 16 | Perfil aluminio V-Slot 20×20 mm | Estructura secundaria | Por cotizar | — | — |
| 17 | Ruedas V Delrin dual V-Slot | Para perfil V-Slot — 80 unidades total | 2 paq. | Por cotizar | — |
| 18 | Filamento PLA 1 kg | Creality — efector UR3 + piezas (3 blanco + 3 negro) | 6 rollos | $350 | $2,100 |
| 19 | Tuerca T Serie 20 M5 | Perfil chico | 80 u. | $2 | $160 |
| 20 | Tornillo T M5 × 8 mm | Perfil chico | 80 u. | $2 | $160 |
| 21 | Rondana M5 plana | — | 80 u. | $1 | $80 |
| 22 | Tuerca T Serie 15 — 5/16"-18 | Perfil grande | 50 u. | $3 | $150 |
| 23 | Tornillo T 5/16"-18 × 3/4" | Perfil grande | 50 u. | $3 | $150 |
| 24 | Tornillo Allen M4 × 30 mm | Ajuste de ruedas G12.9 | 100 u. | $3 | $300 |
| 25 | Tuercas M4 hexagonal | Carbono — 200 unidades total | 2 paq. | $120 | $240 |
| 26 | Espaciadores M4 nylon | 4 mm ID × 12 mm OD | 2 paq. | $130 | $260 |
| 27 | Rodamientos 604ZZ | 4×12×4 mm carbono | 2 paq. | $200 | $400 |

## Eléctrico y tablero

| # | Material | Especificación | Cantidad | Precio unitario (MXN) | Total (MXN) |
| :---: | :--- | :--- | :---: | ---: | ---: |
| 28 | Canaleta ranurada 40×25 mm | Legrand 036205 con tapa, 2 m | 2 | $299 | $598 |
| 29 | Power Supply 24V | Phoenix Contact DIN — protección PLC | 1 | $1,200 | $1,200 |
| 30 | Fuente DC 0–30V laboratorio | 0–10A variable | 2 | $950 | $1,900 |
| 31 | Relevadores PLC Finder | 55.34 24V 4 polos | 4 | $280 | $1,120 |
| 32 | Placa panel | Lámina galvanizada 4×10 c-24 | 1 | $600 | $600 |
| 33 | Botonera industrial | 22 mm — paro / arranque / emergencia | 1 | $450 | $450 |
| 34 | Interruptor termomagnético | ABB 1 polo breaker | 1 | $350 | $350 |
| 35 | Switch TP-Link Gigabit | TL-SG108, 8 puertos | 4 | $600 | $2,400 |
| 36 | Clemas Dinkle DK4N | Terminales separables | 3 | $180 | $540 |
| 37 | Cable calibre 16 | 3 m negro + 3 m blanco + 3 m rojo | 9 m | $25/m | $225 |
| 38 | Alambre calibre 22 AWG | 3 m negro + 3 m azul + 3 m rojo | 9 m | $15/m | $135 |

## Visión artificial y cámaras

| # | Material | Especificación | Cantidad | Precio unitario (MXN) | Total (MXN) |
| :---: | :--- | :--- | :---: | ---: | ---: |
| 39 | Cámara web Logitech C270 | HD 720p con micrófono | 2 | $650 | $1,300 |

## Red y conectividad

| # | Material | Especificación | Cantidad | Precio unitario (MXN) | Total (MXN) |
| :---: | :--- | :--- | :---: | ---: | ---: |
| 40 | Cable Ethernet Cat6 | Blindado, 5 m | 1 | $120 | $120 |

---

## Resumen de costos

| Categoría | Total (MXN) |
| :--- | ---: |
| Control industrial y robótica (HMI) | $1,500 |
| Cómputo y microcontroladores | $4,861 |
| Sensores | $890 |
| Actuadores | $2,530 |
| Estructura mecánica | $3,800 |
| Eléctrico y tablero | $9,518 |
| Visión artificial y cámaras | $1,300 |
| Red y conectividad | $120 |
| **TOTAL ESTIMADO DEL EQUIPO** | **$24,519 MXN** |

{: .highlight }
Los equipos marcados como **Laboratorio IBERO** (UR3, PLC Micro850) son propiedad de la universidad y no representan costo directo para el equipo. Los materiales indicados como **Por cotizar** están pendientes de definir cantidad exacta.

---

## Siguiente sección

[Metodología de Desarrollo](13-metodologia.md)

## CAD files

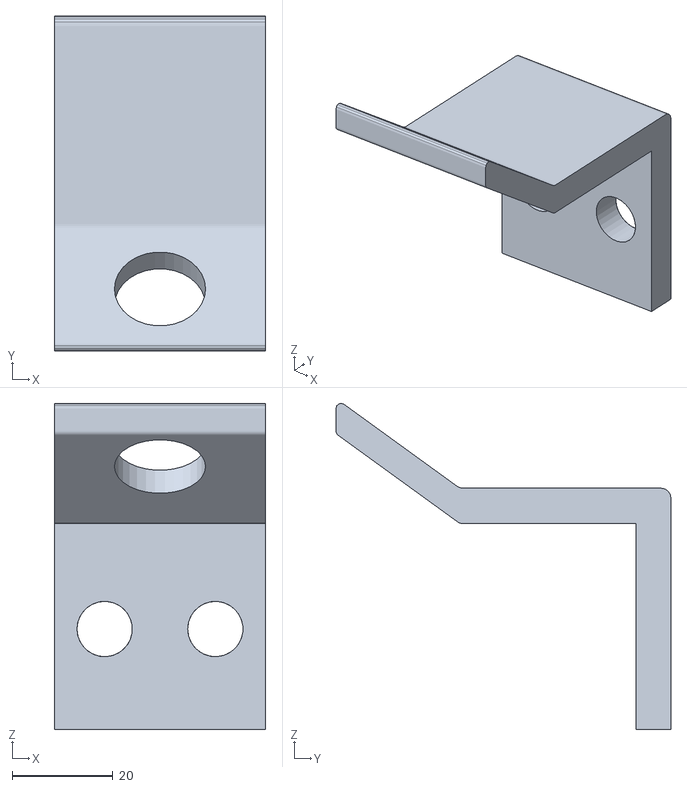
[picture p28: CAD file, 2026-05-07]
assets/0_IMPRIMIR/Sensores.stl
42.0 x 66.6 x 64.9

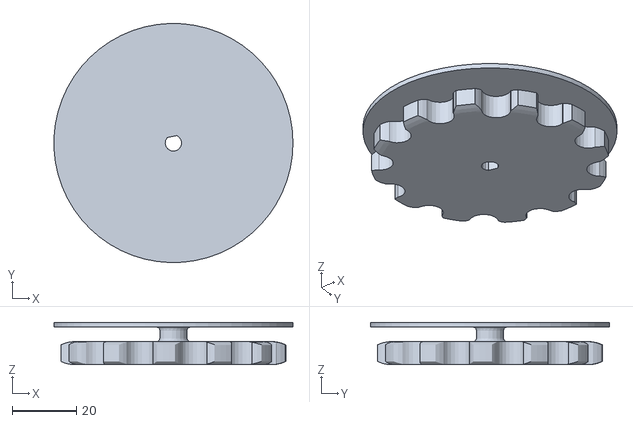
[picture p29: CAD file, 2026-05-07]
assets/0_IMPRIMIR/Engranaje_Plato.stl
74.4 x 74.5 x 13.2

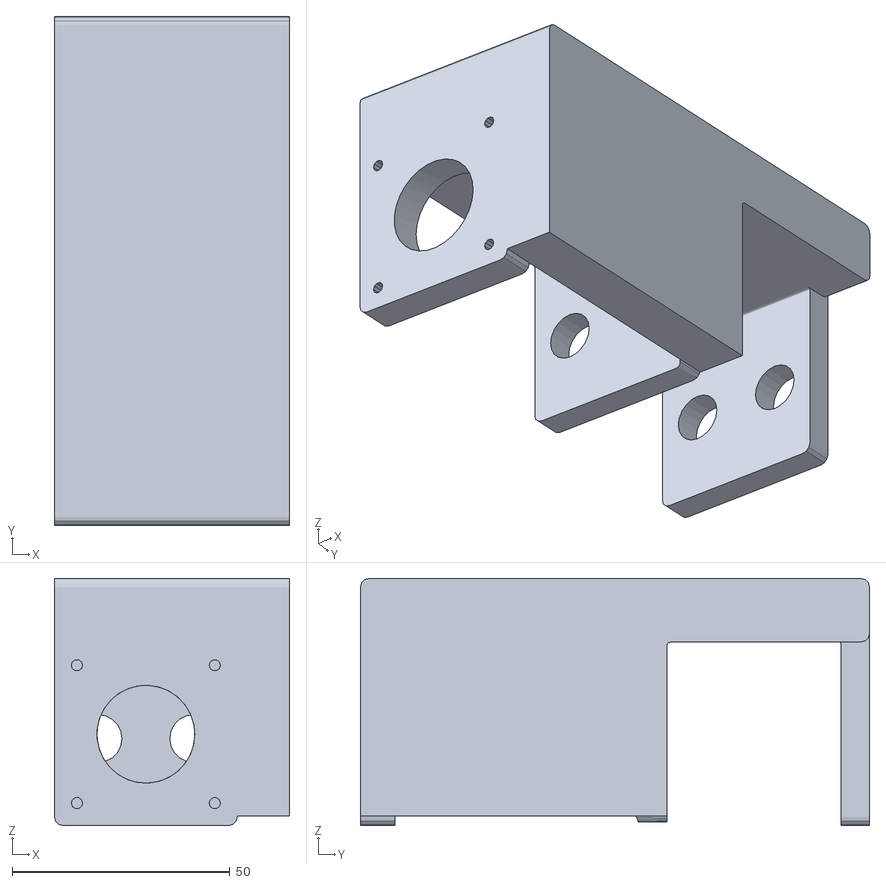
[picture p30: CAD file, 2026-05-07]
assets/0_IMPRIMIR/Agarre_MotroaPasos.stl
54.0 x 117.0 x 56.8

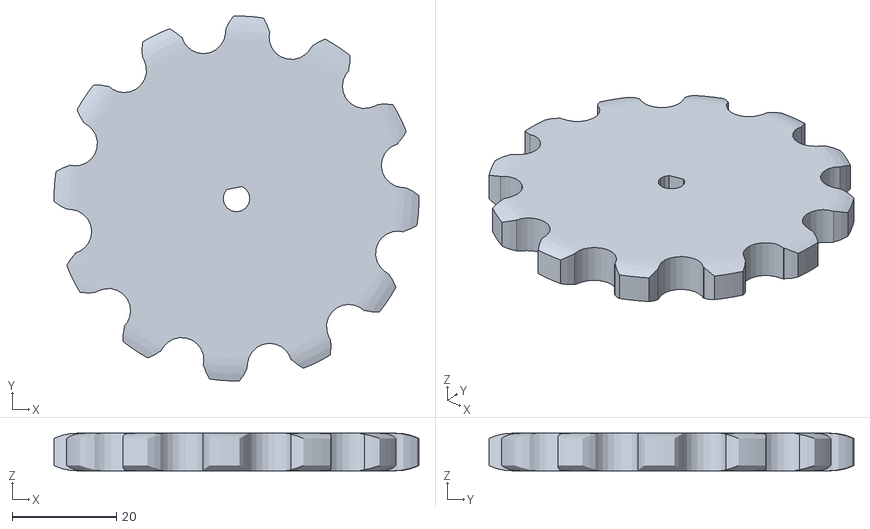
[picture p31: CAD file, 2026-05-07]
assets/0_IMPRIMIR/EngranajeFinal.stl
70.0 x 70.0 x 7.20

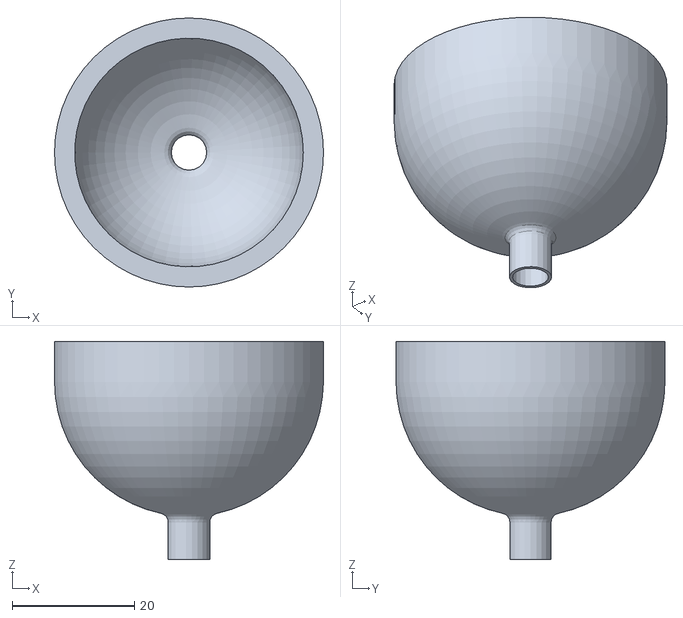
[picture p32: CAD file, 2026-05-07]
assets/0_IMPRIMIR/Gancho.stl
44.1 x 44.1 x 35.7

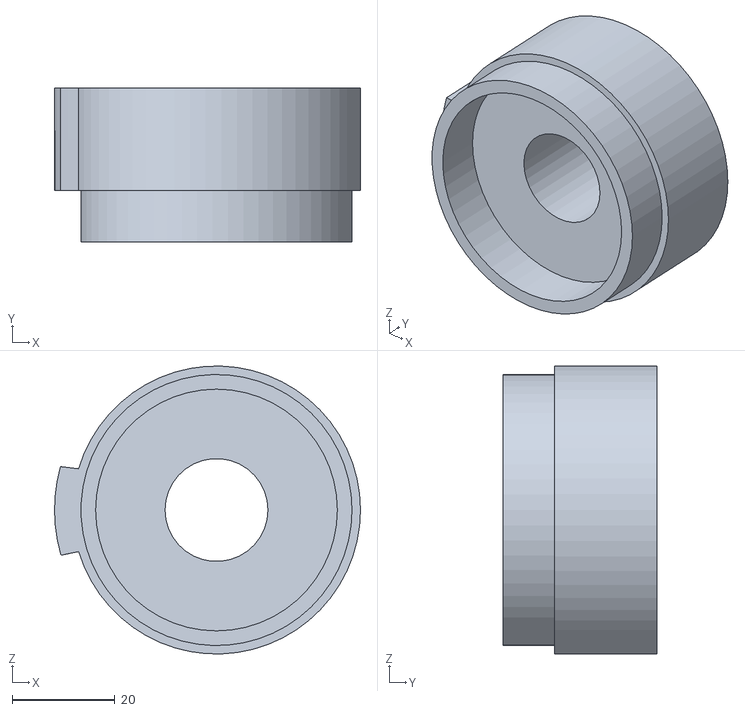
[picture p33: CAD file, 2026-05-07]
assets/0_IMPRIMIR/Soporte lateral de acetato. arribaipt.stl
59.5 x 30.0 x 56.0

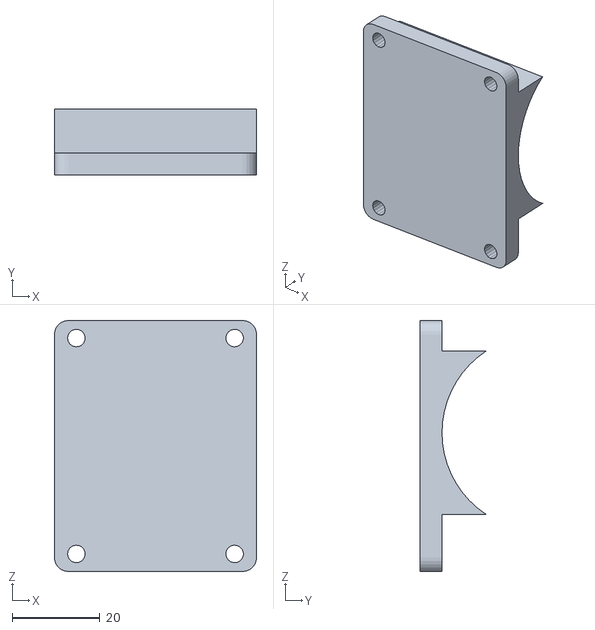
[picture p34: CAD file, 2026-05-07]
assets/0_IMPRIMIR/AgarredePlancha2.stl
46.0 x 15.0 x 57.1

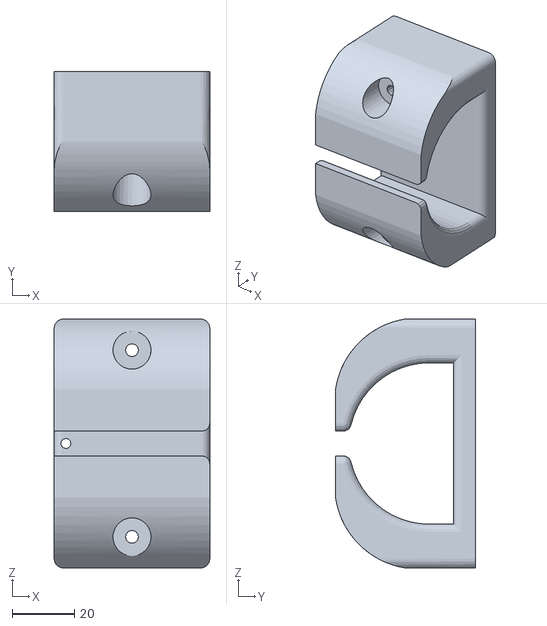
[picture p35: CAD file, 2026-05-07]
assets/0_IMPRIMIR/Carrito_Base.stl
50.0 x 45.0 x 80.0

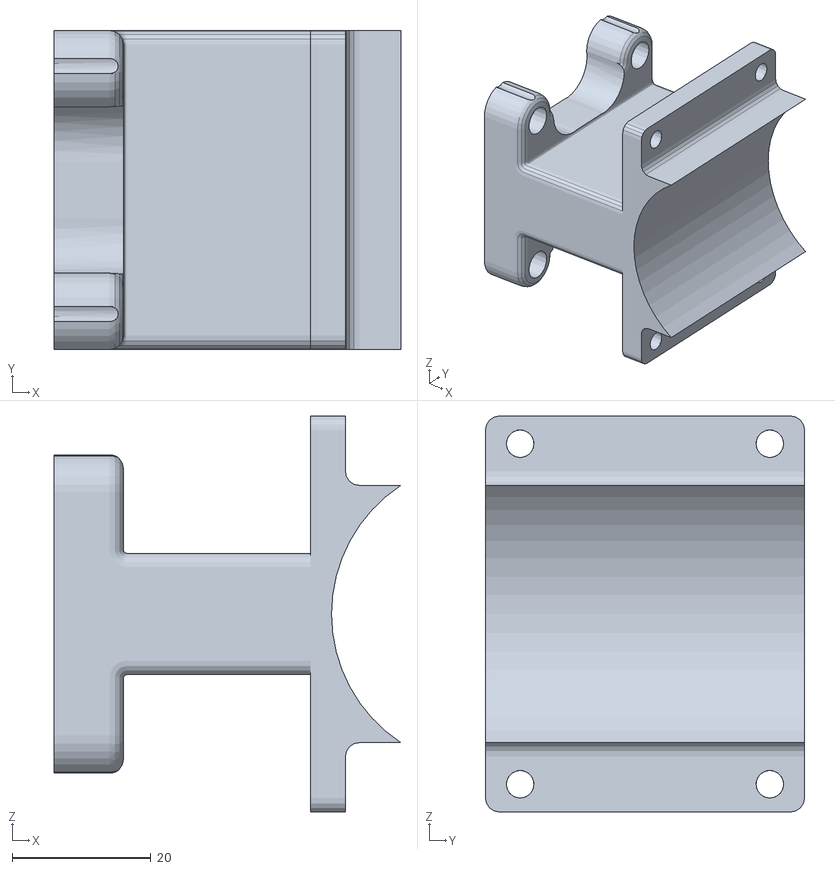
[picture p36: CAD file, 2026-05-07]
assets/0_IMPRIMIR/AgarredePlancha1.stl
50.0 x 46.0 x 57.1

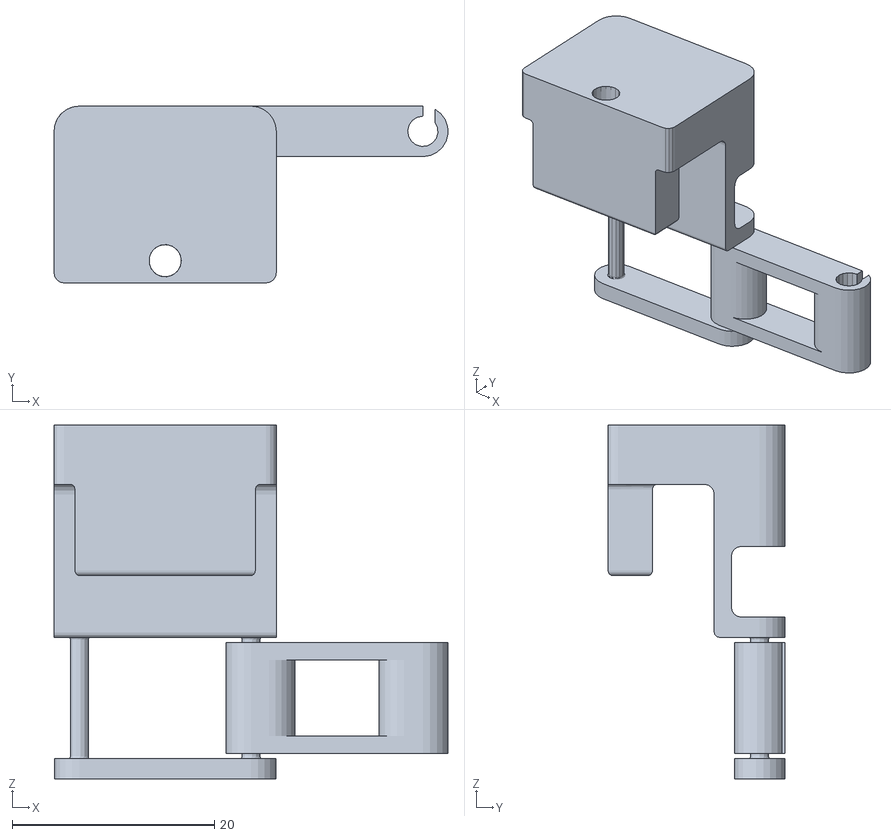
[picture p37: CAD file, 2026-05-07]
assets/0_IMPRIMIR/Cadena_Ganchito.stl
39.0 x 17.5 x 35.0

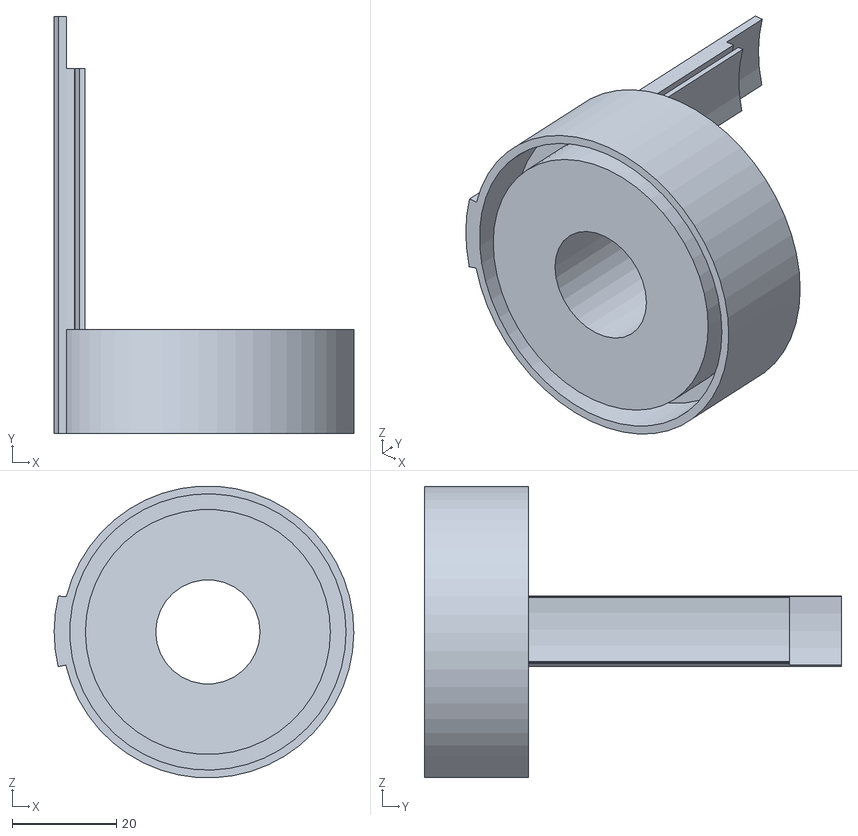
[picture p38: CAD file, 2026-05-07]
assets/0_IMPRIMIR/Soporte lateral de acetato.stl
57.5 x 80.0 x 55.9

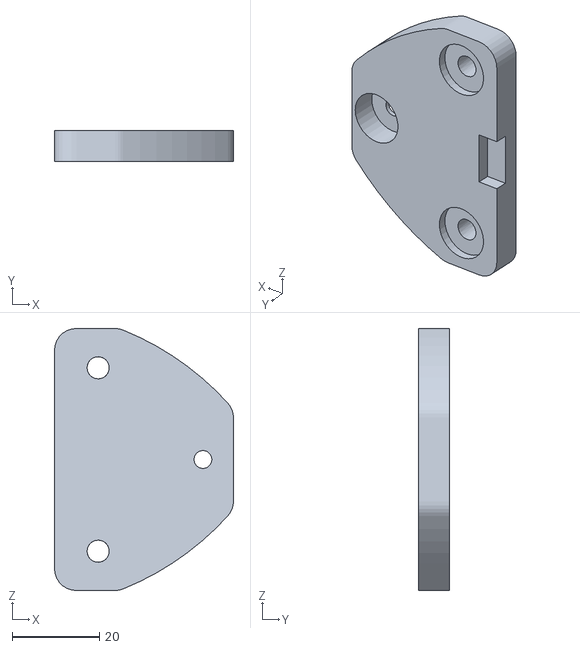
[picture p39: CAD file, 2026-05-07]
assets/0_IMPRIMIR/Cariro_Agarre.stl
41.0 x 7.00 x 60.0

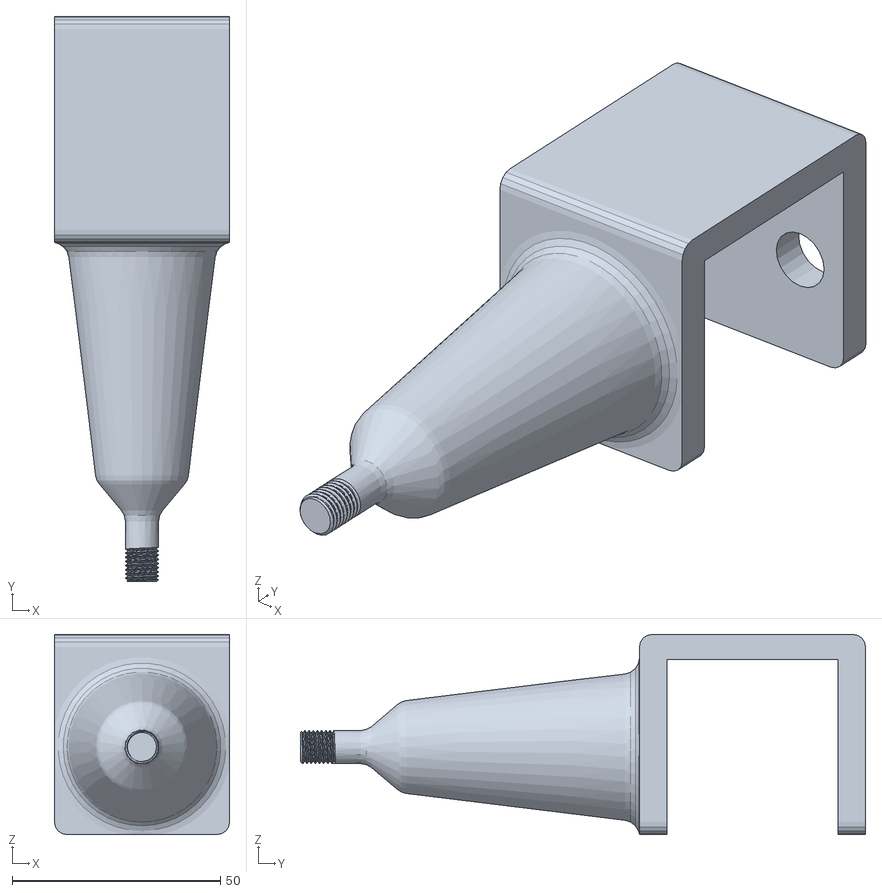
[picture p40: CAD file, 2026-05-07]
assets/0_IMPRIMIR/SoporteTensor.stl
42.0 x 135.5 x 48.0

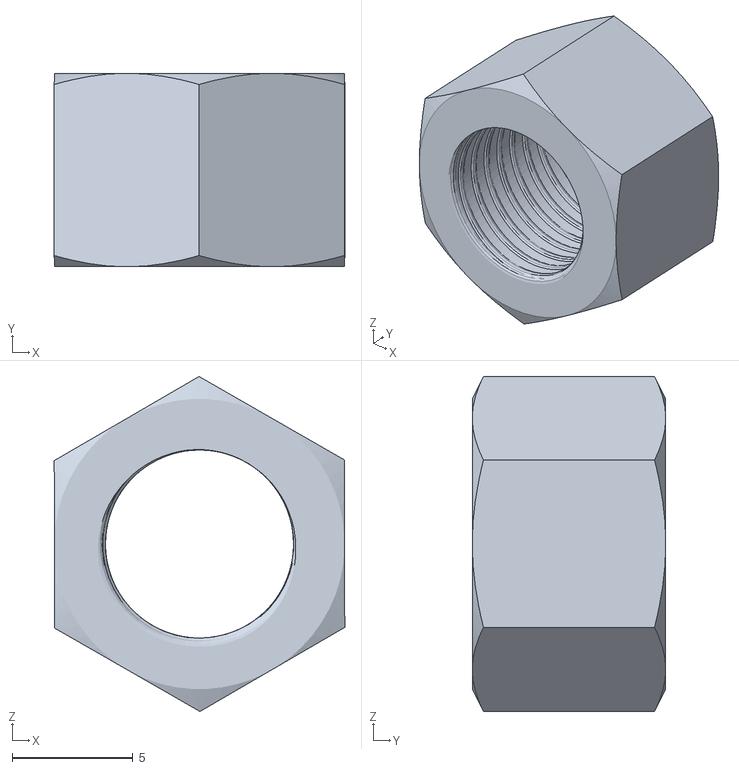
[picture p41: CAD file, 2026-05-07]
assets/0_IMPRIMIR/tuercaTensor.stl
12.0 x 8.00 x 13.9

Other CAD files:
assets/0_IMPRIMIR/Tensores.stl
assets/0_IMPRIMIR/Cadena_Diseño4_final.ipt

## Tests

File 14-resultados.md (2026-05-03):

---
layout: default
title: Resultados
nav_order: 15
---

# Resultados

## Logros del proyecto

El sistema fue implementado y probado de forma exitosa, logrando la **automatización completa del ciclo de planchado** con integración de todos los subsistemas definidos en los objetivos.

---

## Métricas del sistema

| Indicador | Resultado |
| :--- | :--- |
| Objetivos cumplidos | 6 de 6 (100%) |
| Tipos de prenda clasificados por IA | 2 (Camisa / Playera) |
| Waypoints calibrados por rutina | 7 |
| Etapas del proceso automatizado | 8 |
| Intervención humana en el planchado | Ninguna (0%) |
| Prendas procesadas en pruebas (27-28 Abr 2026) | 10 prendas (usuarios 229–239) |
| Subsistemas integrados | 7 (UR3, PLC, Raspberry Pi x2, ESP32, Firebase, HMI) |

---

## Resultados por subsistema

### Robot UR3 — Planchado autónomo
El UR3 ejecuta con éxito las rutinas de planchado diferenciadas para camisa y playera. Los 7 waypoints cubren la superficie completa de la prenda con la presión y velocidad calibradas.

### Clasificación IA — keras_model.h5
El modelo clasificó correctamente las prendas durante todas las pruebas, con niveles de confianza consistentes para seleccionar la rutina correcta del robot. Los resultados fueron registrados en el dashboard en tiempo real.

### PLC Micro850 — Control de campo
El PLC gestionó correctamente el encendido/apagado del motor, la lectura de los tres sensores y la activación de la plancha eléctrica durante todos los ciclos de prueba, sin errores de comunicación Modbus.

### Interfaz web — En producción
La plataforma está desplegada y funcional en [luiscortesmunoz.github.io/Planchaduria](https://luiscortesmunoz.github.io/Planchaduria/). Usuarios reales utilizaron el sistema durante las pruebas finales (usuarios 229–239), registrando sus prendas, obteniendo QR y monitoreando el estado en tiempo real.

### Firebase — Trazabilidad completa
Cada prenda procesada quedó registrada en Firebase con: ID de pedido, datos del usuario, tipo de prenda detectado por IA, nivel de confianza, fotografía de evidencia y estado final del pedido.

### HMI — Validación por QR
El HMI leyó correctamente los códigos QR presentados por los usuarios y habilitó el inicio del proceso físico tras validar el ID contra Firebase.

---

## Evidencia de prendas procesadas

Las siguientes fotografías fueron capturadas automáticamente por la cámara Raspberry Pi durante las pruebas del 27–28 de abril de 2026 y almacenadas en Firebase Storage:

| ID Usuario | Fecha y hora | Almacenamiento |
| :--- | :--- | :--- |
| 229 | 27 Abr 2026 · 17:20 | Firebase Storage |
| 230 | 27 Abr 2026 · 19:05 | Firebase Storage |
| 231 | 27 Abr 2026 · 19:12 | Firebase Storage |
| 233 | 27 Abr 2026 · 20:35 | Firebase Storage |
| 234 | 27 Abr 2026 · 20:39 | Firebase Storage |
| 235 | 27 Abr 2026 · 20:42 | Firebase Storage |
| 236 | 27 Abr 2026 · 20:56 | Firebase Storage |
| 237 | 28 Abr 2026 · 21:17 | Firebase Storage |
| 238 | 28 Abr 2026 · 21:25 | Firebase Storage |
| 239 | 28 Abr 2026 · 21:39 | Firebase Storage |

---

## Siguiente sección

[Problemas Encontrados](15-problemas.md)

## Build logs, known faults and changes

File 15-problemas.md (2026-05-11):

---
layout: default
title: Problemas Encontrados
nav_order: 16
---

# Problemas Encontrados

## Retos técnicos durante el desarrollo

A lo largo del proyecto se identificaron y resolvieron múltiples retos de integración, comunicación y sincronización entre subsistemas.

---

## 1. Sincronización Modbus TCP multi-dispositivo

**Problema:** La comunicación simultánea con el PLC (`192.168.3.151`) y el UR3 (`192.168.3.71`) por Modbus TCP generaba conflictos de timing. Peticiones concurrentes causaban timeouts o lecturas incorrectas de sensores.

**Solución:** Se implementó un sistema de **máscaras de sensores por etapa** (`configurar_mascaras_sensores`). Solo el sensor relevante para la etapa actual está habilitado, reduciendo el número de peticiones Modbus simultáneas y el riesgo de conflictos. El polling de sensores se fijó en 100 ms.

---

## 2. Ruido eléctrico en sensores inductivos

**Problema:** Los sensores inductivos S2 y S3 presentaron lecturas inestables debido a rebotes mecánicos de la banda y ruido eléctrico del motor. Esto provocaba falsas activaciones que podían iniciar el UR3 en el momento incorrecto.

**Solución:** Implementación de un **filtro de debounce** que requiere 3 lecturas consecutivas positivas en 50 ms para validar el estado de un sensor:

```python
LECTURAS_DEBOUNCE = 3
TIEMPO_DEBOUNCE   = 0.05  # segundos
```

---

## 3. Clasificación IA con iluminación variable

**Problema:** El modelo [`keras_model.h5`](assets/files/keras_model.h5) presentó variabilidad en el nivel de confianza de clasificación cuando la iluminación del laboratorio cambiaba (luz natural vs. artificial).

**Solución:** Se implementaron **reintentos automáticos** (hasta 3 intentos con 2 segundos de espera) para la captura de fotografía, y se mejoró la iluminación fija de la estación de foto con luz artificial constante.

```python
REINTENTOS_FOTO       = 3
TIEMPO_ENTRE_REINTENTOS = 2.0  # segundos
```

---

## 4. Latencia del backend en Render (arranque en frío)

**Problema:** El plan gratuito de Render suspende el contenedor Docker tras 15 minutos de inactividad. La primera petición tras la suspensión tiene una latencia de 30–60 segundos, lo que podía bloquear la rutina maestra.

**Solución (mitigada):** Se implementó un mecanismo de reintentos en la rutina maestra para las peticiones al backend, permitiendo hasta 3 intentos antes de reportar el error. No se eliminó el problema de fondo, pero se evita que el sistema falle por un solo timeout.

---

## 5. Calibración de waypoints del UR3

**Problema:** La calibración manual de los 7 waypoints para cada tipo de prenda requirió múltiples iteraciones. Las diferencias en la posición de la prenda sobre la banda generaban cobertura incompleta de la superficie en algunos puntos.

**Solución:** Proceso iterativo de calibración en PolyScope: posicionar el robot manualmente → guardar waypoint → ejecutar trayectoria completa → evaluar cobertura → ajustar. Se realizaron aproximadamente 8 iteraciones por rutina hasta lograr cobertura completa sin colisiones.

---

## 6. Gestión de estados concurrentes

**Problema:** La rutina maestra debía manejar simultáneamente el estado del PLC, el robot, la cámara y Firebase, además de responder a errores en cualquiera de estas capas sin bloquear el proceso principal.

**Solución:** Arquitectura de **etapas explícitas** con la función `cambiar_etapa()`, que garantiza que cada subsistema solo está activo durante su etapa correspondiente. El uso de threading controlado  [`dashboard_server.py`](assets/files/dashboard_server.py) permite monitorear el proceso sin interferir con él.

---

## Mejoras futuras identificadas

- Visión por computadora para **detección de arrugas** post-planchado (verificación de calidad)
- **Control PID de temperatura** de la plancha en tiempo real
- Soporte para más tipos de prendas (pantalones, vestidos)
- **Notificaciones push** al cliente cuando la prenda está lista
- Optimización de trayectorias del UR3 con algoritmos de motion planning
- Redundancia en la comunicación Modbus con reconexión automática

---

## Siguiente sección

[Evidencia Visual](16-evidencia.md)

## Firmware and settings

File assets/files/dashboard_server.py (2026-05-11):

# Step 1: Dashboard server externo para observar tu rutina sin modificarla
# Ejecuta tu código original como subproceso y lee sus prints en consola.
# Requisito: guarda tu rutina original como "rutina_maestra.py" junto a este archivo
# o ejecuta con: ROUTINE_FILE="nombre_de_tu_codigo.py" python dashboard_server.py

import json
import os
import queue
import re
import subprocess
import sys
import threading
import time
from datetime import datetime
from pathlib import Path
from typing import Any, Dict, List

from flask import Flask, Response, jsonify, send_from_directory

# Step 2: Configuración
APP_DIR = Path(__file__).resolve().parent
WEB_DIR = APP_DIR / "web_dashboard"

ROUTINE_FILE = Path(os.getenv("ROUTINE_FILE", "rutina_maestra.py"))
if not ROUTINE_FILE.is_absolute():
    ROUTINE_FILE = APP_DIR / ROUTINE_FILE

HOST = os.getenv("DASHBOARD_HOST", "0.0.0.0")
PORT = int(os.getenv("DASHBOARD_PORT", "5050"))
AUTO_START_ROUTINE = os.getenv("AUTO_START_ROUTINE", "1") == "1"
MAX_LOG_LINES = int(os.getenv("MAX_LOG_LINES", "120"))

# Step 3: Etapas reales detectadas en tu código original
STAGES: List[Dict[str, str]] = [
    {
        "key": "ESPERA_SENSOR1",
        "label": "Sensor 1",
        "description": "Espera detección inicial de prenda",
    },
    {
        "key": "AVANCE_45S_ANTES_FOTO",
        "label": "Avance foto",
        "description": "Motor avanza antes de captura",
    },
    {
        "key": "FOTO",
        "label": "Foto / IA",
        "description": "Captura, descarga y subida de foto",
    },
    {
        "key": "AVANCE_A_SENSOR2",
        "label": "Sensor 2",
        "description": "Avance hasta posición del UR3",
    },
    {
        "key": "UR3",
        "label": "UR3",
        "description": "Clasificación y rutina del robot",
    },
    {
        "key": "AVANCE_A_SENSOR3",
        "label": "Sensor 3",
        "description": "Avance hacia etapa de salida",
    },
    {
        "key": "PISTON",
        "label": "Pistón",
        "description": "Extensión, retracción y paro",
    },
    {
        "key": "AVANCE_FINAL_60S",
        "label": "Avance final",
        "description": "Salida final antes de STOP",
    },
]

STAGE_INDEX = {stage["key"]: i for i, stage in enumerate(STAGES)}
STAGE_LABEL = {stage["key"]: stage["label"] for stage in STAGES}

# Step 4: Estado compartido del dashboard
state_lock = threading.Lock()
subscribers_lock = threading.Lock()
subscribers: List[queue.Queue] = []
routine_process = None
reader_thread = None

state: Dict[str, Any] = {
    "dashboard_started_at": datetime.now().isoformat(timespec="seconds"),
    "last_update": datetime.now().isoformat(timespec="seconds"),
    "routine_file": str(ROUTINE_FILE),
    "routine_process_running": False,
    "routine_pid": None,
    "status": "idle",  # idle | running | success | error | stopped
    "current_stage": "STOP",
    "current_stage_label": "STOP / Reposo",
    "current_stage_index": -1,
    "last_non_stop_stage": "STOP",
    "last_non_stop_stage_label": "STOP / Reposo",
    "order_id": "",
    "usuario": "",
    "cantidad": "",
    "tipo_prenda": "",
    "confianza_ia": "",
    "ultima_foto_local": "",
    "motor_encendido": False,
    "senal_000007_activada": None,
    "sensor_masks": {"s1": False, "s2": False, "s3": False},
    "error": {
        "active": False,
        "stage": "",
        "stage_label": "",
        "message": "",
        "timestamp": "",
    },
    "logs": [],
    "stages": STAGES,
}

app = Flask(__name__, static_folder=str(WEB_DIR), static_url_path="")


def now_iso() -> str:
    return datetime.now().isoformat(timespec="seconds")


def safe_bool_from_on_off(value: str) -> bool:
    return value.strip().upper() == "ON"


def append_log(line: str) -> None:
    line = line.rstrip("\n")
    if not line:
        return

    record = {
        "time": datetime.now().strftime("%H:%M:%S"),
        "line": line,
    }

    state["logs"].append(record)
    if len(state["logs"]) > MAX_LOG_LINES:
        state["logs"] = state["logs"][-MAX_LOG_LINES:]


def set_stage(stage_key: str) -> None:
    stage_key = stage_key.strip()
    index = STAGE_INDEX.get(stage_key, -1)

    state["current_stage"] = stage_key
    state["current_stage_index"] = index

    if stage_key == "STOP":
        state["current_stage_label"] = "STOP / Reposo"
    else:
        state["current_stage_label"] = STAGE_LABEL.get(stage_key, stage_key)
        state["last_non_stop_stage"] = stage_key
        state["last_non_stop_stage_label"] = STAGE_LABEL.get(stage_key, stage_key)
        if not state["error"]["active"]:
            state["status"] = "running"


def clear_error() -> None:
    state["error"] = {
        "active": False,
        "stage": "",
        "stage_label": "",
        "message": "",
        "timestamp": "",
    }


def set_error(message: str) -> None:
    failed_stage = state.get("last_non_stop_stage") or state.get("current_stage") or "STOP"
    failed_label = STAGE_LABEL.get(failed_stage, failed_stage)

    state["status"] = "error"
    state["error"] = {
        "active": True,
        "stage": failed_stage,
        "stage_label": failed_label,
        "message": message.strip() or "Error no especificado",
        "timestamp": now_iso(),
    }


def snapshot_state() -> Dict[str, Any]:
    with state_lock:
        return json.loads(json.dumps(state, ensure_ascii=False))


def broadcast_state() -> None:
    payload = json.dumps(snapshot_state(), ensure_ascii=False)

    with subscribers_lock:
        dead_clients = []
        for client_queue in subscribers:
            try:
                client_queue.put_nowait(payload)
            except Exception:
                dead_clients.append(client_queue)

        for client_queue in dead_clients:
            if client_queue in subscribers:
                subscribers.remove(client_queue)


def parse_log_line(raw_line: str) -> None:
    line = raw_line.strip()
    if not line:
        return

    with state_lock:
        append_log(line)
        state["last_update"] = now_iso()

        # Etapa actual: ya existe en tu función cambiar_etapa()
        match_stage = re.search(r"\[ESTADO\]\s*Etapa actual\s*->\s*(.+)$", line)
        if match_stage:
            set_stage(match_stage.group(1))

        # Inicio de pedido
        match_order = re.search(
            r"\[PC\]\s*Iniciando pedido id=(.*?)\s*\|\s*usuario=(.*?)\s*\|\s*cantidad=(.*?)\s*\|\s*tipo_prenda=(.*)$",
            line,
        )
        if match_order:
            clear_error()
            state["status"] = "running"
            state["order_id"] = match_order.group(1).strip()
            state["usuario"] = match_order.group(2).strip()
            state["cantidad"] = match_order.group(3).strip()
            state["tipo_prenda"] = match_order.group(4).strip()
            state["confianza_ia"] = ""
            state["ultima_foto_local"] = ""
            state["last_non_stop_stage"] = "STOP"
            state["last_non_stop_stage_label"] = "STOP / Reposo"

        # Nuevo pedido detectado, útil cuando aún no entra a ejecutar_pedido()
        if "[PC] Nuevo pedido detectado:" in line and not state["error"]["active"]:
            state["status"] = "running"

        # Pedido terminado correctamente
        if "[PC] Pedido finalizado" in line:
            clear_error()
            state["status"] = "success"

        # Sin pedidos pendientes
        if "[PC] Sin pedidos pendientes" in line and not state["error"]["active"]:
            if not state["routine_process_running"]:
                state["status"] = "stopped"
            elif state["current_stage"] == "STOP":
                state["status"] = "idle"

        # Motor
        if "[PLC] Motor iniciado" in line:
            state["motor_encendido"] = True
        elif "[PLC] Motor detenido" in line:
            state["motor_encendido"] = False

        # Señal 000007 / plancha
        if "PLANCHA ACTIVADA" in line:
            state["senal_000007_activada"] = True
        elif "PLANCHA DESACTIVADA" in line:
            state["senal_000007_activada"] = False

        # Máscaras de sensores
        match_masks = re.search(
            r"\[MASCARAS\].*S1=(ON|OFF).*S2=(ON|OFF).*S3=(ON|OFF)",
            line,
        )
        if match_masks:
            state["sensor_masks"] = {
                "s1": safe_bool_from_on_off(match_masks.group(1)),
                "s2": safe_bool_from_on_off(match_masks.group(2)),
                "s3": safe_bool_from_on_off(match_masks.group(3)),
            }

        # Foto local
        match_photo = re.search(r"\[IA\]\s*Última foto local actualizada:\s*(.+)$", line)
        if match_photo:
            state["ultima_foto_local"] = match_photo.group(1).strip()

        # Clasificación IA
        match_ai = re.search(
            r"\[IA\]\s*Prenda detectada:\s*(.*?)\s*\|\s*confianza=([0-9.]+)",
            line,
        )
        if match_ai:
            state["tipo_prenda"] = match_ai.group(1).strip()
            state["confianza_ia"] = match_ai.group(2).strip()

        # Errores: se guarda la etapa en la que estaba antes de que tu código mande STOP
        match_error_order = re.search(r"\[PC\]\s*Error en pedido:\s*(.+)$", line)
        if match_error_order:
            set_error(match_error_order.group(1))

        match_error_loop = re.search(r"\[PC\]\s*Error en loop principal:\s*(.+)$", line)
        if match_error_loop:
            set_error(match_error_loop.group(1))

        # Errores no controlados del proceso Python
        if "Traceback (most recent call last):" in line:
            set_error("Traceback no controlado en la rutina. Revisa el log técnico.")

    broadcast_state()


def read_process_output(proc: subprocess.Popen) -> None:
    global routine_process

    try:
        assert proc.stdout is not None
        for raw_line in proc.stdout:
            parse_log_line(raw_line)
    except Exception as exc:
        parse_log_line(f"[DASHBOARD] Error leyendo salida de rutina: {exc}")
    finally:
        return_code = proc.poll()
        with state_lock:
            state["routine_process_running"] = False
            state["routine_pid"] = None
            state["last_update"] = now_iso()
            append_log(f"[DASHBOARD] Proceso de rutina terminado. return_code={return_code}")
            if state["status"] not in ["error", "success"]:
                state["status"] = "stopped"
        broadcast_state()


def start_routine_process() -> bool:
    global routine_process, reader_thread

    with state_lock:
        if routine_process is not None and routine_process.poll() is None:
            return True

        state["routine_file"] = str(ROUTINE_FILE)
        state["last_update"] = now_iso()

    if not ROUTINE_FILE.exists():
        with state_lock:
            set_error(
                f"No encontré la rutina original en: {ROUTINE_FILE}. "
                "Guarda tu código como rutina_maestra.py o define ROUTINE_FILE."
            )
            append_log(f"[DASHBOARD] Archivo no encontrado: {ROUTINE_FILE}")
        broadcast_state()
        return False

    routine_process = subprocess.Popen(
        [sys.executable, "-u", str(ROUTINE_FILE)],
        cwd=str(ROUTINE_FILE.parent),
        stdout=subprocess.PIPE,
        stderr=subprocess.STDOUT,
        text=True,
        encoding="utf-8",
        errors="replace",
        bufsize=1,
    )

    with state_lock:
        clear_error()
        state["status"] = "running"
        state["routine_process_running"] = True
        state["routine_pid"] = routine_process.pid
        state["last_update"] = now_iso()
        append_log(f"[DASHBOARD] Rutina iniciada como subproceso PID={routine_process.pid}")

    reader_thread = threading.Thread(target=read_process_output, args=(routine_process,), daemon=True)
    reader_thread.start()
    broadcast_state()
    return True


@app.route("/")
def index():
    return send_from_directory(WEB_DIR, "index.html")


@app.route("/<path:path>")
def static_files(path: str):
    return send_from_directory(WEB_DIR, path)


@app.route("/api/status")
def api_status():
    return jsonify(snapshot_state())


@app.route("/api/start", methods=["POST"])
def api_start():
    ok = start_routine_process()
    return jsonify({"ok": ok, "state": snapshot_state()})


@app.route("/events")
def events():
    client_queue: queue.Queue = queue.Queue(maxsize=20)
    with subscribers_lock:
        subscribers.append(client_queue)

    def stream():
        try:
            yield f"data: {json.dumps(snapshot_state(), ensure_ascii=False)}\n\n"
            while True:
                try:
                    payload = client_queue.get(timeout=20)
                    yield f"data: {payload}\n\n"
                except queue.Empty:
                    yield ": keep-alive\n\n"
        finally:
            with subscribers_lock:
                if client_queue in subscribers:
                    subscribers.remove(client_queue)

    return Response(stream(), mimetype="text/event-stream")


if __name__ == "__main__":
    if AUTO_START_ROUTINE:
        start_routine_process()

    print(f"[DASHBOARD] Abre el tablero en http://localhost:{PORT}")
    print(f"[DASHBOARD] Rutina observada: {ROUTINE_FILE}")
    app.run(host=HOST, port=PORT, debug=False, threaded=True)

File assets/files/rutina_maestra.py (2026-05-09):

# Paso 1: Librerías
import os
os.environ["TF_USE_LEGACY_KERAS"] = "1"

import os
import re
import time
import socket
from datetime import datetime
from typing import Tuple, Optional
import numpy as np
from PIL import Image, ImageOps
import tf_keras as keras
from tf_keras.models import load_model

import requests
from pymodbus.client import ModbusTcpClient
import serial
import serial.tools.list_ports

# Paso 2: Configuración general
RENDER_BASE_URL = "https://docker-planchaduria.onrender.com"

# Raspberry con cámara
RASPBERRY_IP = "192.168.3.162"
RASPBERRY_PORT = 5000
BASE_RPI = f"http://{RASPBERRY_IP}:{RASPBERRY_PORT}"

# PLC
PLC_IP = "192.168.3.151"
PLC_PORT = 502
PLC_UNIT_ID = 1

# Direcciones PLC (offset base 0)
COIL_CMD_START = 0      # 000001
COIL_CMD_STOP = 1       # 000002
COIL_CMD_DIR_FWD = 2    # 000003

SENSOR1_ADDRESS = 3     # 000004
SENSOR2_ADDRESS = 4     # 000005
SENSOR3_ADDRESS = 5     # 000006
SALIDA_AUX_000007 = 6   # 000007 / Plancha

# Modelo IA
MODEL_PATH = "keras_model.h5"
LABELS_PATH = "labels.txt"
IMG_SIZE_MODELO = (224, 224)

# Robot UR3
ROBOT_IP = "192.168.3.71"
ROBOT_PORT = 30002

# ESP32 por serial
ESP32_SERIAL_PORT = "COM3"   # CAMBIA ESTO SI ES NECESARIO
ESP32_BAUDRATE = 115200
ESP32_TIMEOUT = 1

# Carpeta local para fotos
CARPETA_PC = "fotos_pc"
os.makedirs(CARPETA_PC, exist_ok=True)

# Paso 2.1: Tiempos principales de proceso
TIEMPO_PULSO = 0.2
TIEMPO_POLL = 2.0
TIEMPO_POLL_SENSOR = 0.1
TIEMPO_POLL_CONTINUO = 0.1

# Etapa 1: después de detectar Sensor 1, avanzar 45 segundos y detener para foto
TIEMPO_AVANCE_ANTES_FOTO = 45.0

# Etapa UR3
TIEMPO_RUTINA_UR3 = 15.0

# Cámara
TIEMPO_ESPERA_FOTO = 0.8

# Piston
TIEMPO_PISTON_ABIERTO = 9.0
TIEMPO_ESPERA_TRAS_CERRAR = 9.0

# Finalización: después del pistón, avanzar exactamente 1 minuto y terminar
TIEMPO_AVANCE_FINAL_STOP = 60.0

# Torreta
TIEMPO_PARPADEO_ESPERA_SENSOR1 = 0.3
TIEMPO_FLASH_FOTO = 0.25

# Debounce / filtro contra ruido eléctrico o rebotes mecánicos
LECTURAS_DEBOUNCE = 3
TIEMPO_DEBOUNCE = 0.05

# Reintentos
REINTENTOS_FOTO = 3
TIEMPO_ENTRE_REINTENTOS = 2.0

# Rutinas UR3
RUTA_SCRIPT_CAMISA = "camisa.script"
RUTA_SCRIPT_PLAYERA = "playera.script"

# Rutina vestido
Q_VESTIDO = [0.0, -1.57, 1.57, -1.57, 0.0, 0.0]
A_VESTIDO = 0.4
V_VESTIDO = 0.25


# Paso 3: Variables globales
procesando = False
motor_continuo_activo = False
pedido_actual_id = ""
usuario_actual = ""
cantidad_actual = 0
ur3_ya_ejecutado = False
estado_inicio_reportado = False
estado_planchado_reportado = False
tipo_prenda_actual = ""
esp32_serial = None
motor_encendido = False
senal_000007_activada = False
reinicio_despues_ur3 = False
modo_torreta = "rojo"
ultima_foto_local = ""
modelo_prendas = None
labels_prendas = []

# Máscaras de sensores por etapa
sensor1_habilitado = False
sensor2_habilitado = False
sensor3_habilitado = False
etapa_actual = "STOP"


# Paso 4: Utilidades
def limpiar_usuario(usuario: str) -> str:
    usuario = str(usuario).strip()
    usuario = re.sub(r"[^0-9]", "", usuario)

    if usuario == "":
        raise RuntimeError("El usuario no puede estar vacío")

    if len(usuario) > 5:
        raise RuntimeError("El usuario debe tener máximo 5 dígitos")

    return usuario


def imprimir_respuesta_http(resp: requests.Response, etiqueta: str):
    print(f"[HTTP] {etiqueta} status={resp.status_code}")
    try:
        print(f"[HTTP] {etiqueta} json={resp.json()}")
    except Exception:
        print(f"[HTTP] {etiqueta} text={resp.text[:1000]}")


def obtener_usuario_desde_order(order_data: dict) -> str:
    contador = order_data.get("Contador", "")
    folio = order_data.get("Folio", "")

    if contador not in [None, ""]:
        return limpiar_usuario(str(contador))

    digitos = re.sub(r"[^0-9]", "", str(folio))
    if digitos != "":
        return limpiar_usuario(digitos)

    raise RuntimeError("No se pudo obtener un usuario numérico válido del pedido")


def cambiar_etapa(nueva_etapa: str):
    global etapa_actual
    etapa_actual = nueva_etapa
    print(f"[ESTADO] Etapa actual -> {etapa_actual}")


def configurar_mascaras_sensores(s1: bool, s2: bool, s3: bool):
    global sensor1_habilitado, sensor2_habilitado, sensor3_habilitado
    sensor1_habilitado = s1
    sensor2_habilitado = s2
    sensor3_habilitado = s3
    print(
        "[MASCARAS] "
        f"S1={'ON' if s1 else 'OFF'} | "
        f"S2={'ON' if s2 else 'OFF'} | "
        f"S3={'ON' if s3 else 'OFF'}"
    )


def cargar_modelo_prendas():
    global modelo_prendas, labels_prendas

    if modelo_prendas is None:
        if not os.path.exists(MODEL_PATH):
            raise RuntimeError(f"No existe el archivo del modelo: {MODEL_PATH}")

        if not os.path.exists(LABELS_PATH):
            raise RuntimeError(f"No existe el archivo de etiquetas: {LABELS_PATH}")

        print(f"[IA] Cargando modelo desde {MODEL_PATH} ...")
        modelo_prendas = load_model(MODEL_PATH, compile=False)
        print("[IA] Modelo cargado correctamente")

        with open(LABELS_PATH, "r", encoding="utf-8") as f:
            labels_prendas = [line.strip() for line in f if line.strip()]

        print(f"[IA] Etiquetas cargadas: {labels_prendas}")

    return modelo_prendas, labels_prendas


def normalizar_etiqueta_modelo(texto: str) -> str:
    t = (texto or "").strip().lower()

    # Por si viene como "0 Camisa"
    t = re.sub(r"^\d+\s*", "", t)

    reemplazos = {"á": "a", "é": "e", "í": "i", "ó": "o", "ú": "u"}
    for a, b in reemplazos.items():
        t = t.replace(a, b)

    if "playera" in t or "playeras" in t:
        return "playera"
    if "camisa" in t or "camisas" in t:
        return "camisa"
    if "vestido" in t or "vestidos" in t:
        return "vestido"

    return t


def clasificar_prenda_por_ia(ruta_imagen: str) -> Tuple[str, float]:
    if not os.path.exists(ruta_imagen):
        raise RuntimeError(f"No existe la imagen para clasificar: {ruta_imagen}")

    modelo, labels = cargar_modelo_prendas()

    image = Image.open(ruta_imagen).convert("RGB")
    image = ImageOps.fit(image, IMG_SIZE_MODELO, Image.Resampling.LANCZOS)

    image_array = np.asarray(image).astype(np.float32)
    image_array = (image_array / 127.5) - 1.0
    data = np.expand_dims(image_array, axis=0)

    prediction = modelo.predict(data, verbose=0)[0]
    idx = int(np.argmax(prediction))
    confianza = float(prediction[idx])

    if idx < 0 or idx >= len(labels):
        raise RuntimeError(f"Índice de clase fuera de rango: {idx}")

    clase = normalizar_etiqueta_modelo(labels[idx])
    return clase, confianza


# Paso 4.1: ESP32 serial
def listar_puertos_serial():
    puertos = serial.tools.list_ports.comports()
    print("[ESP32] Puertos seriales detectados:")
    for p in puertos:
        print(f" - {p.device} | {p.description}")
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
